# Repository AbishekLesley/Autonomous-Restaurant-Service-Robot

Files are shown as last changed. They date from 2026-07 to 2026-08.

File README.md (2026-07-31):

# 🤖 Autonomous Restaurant Service Robot

> An autonomous restaurant delivery robot developed to automate food delivery within indoor environments using magnetic-guided navigation, wireless communication, and embedded control systems.

---

## 📌 Overview

This project presents an autonomous service robot capable of navigating predefined paths inside restaurants while carrying food safely and efficiently. The robot integrates embedded systems, custom PCB design, motor control, wireless communication, and a mobile application into a complete autonomous platform.

### Key Features

- Autonomous restaurant delivery
- Magnetic path following using Hall-effect sensors
- Dual microcontroller architecture (ESP32-S3 + STM32)
- PID-based motor control
- Wireless communication
- Mobile application interface
- Obstacle detection
- Autonomous charging dock
- Custom-designed PCBs
- Custom enclosure design

---

## 🏗 System Architecture

<p align="center">
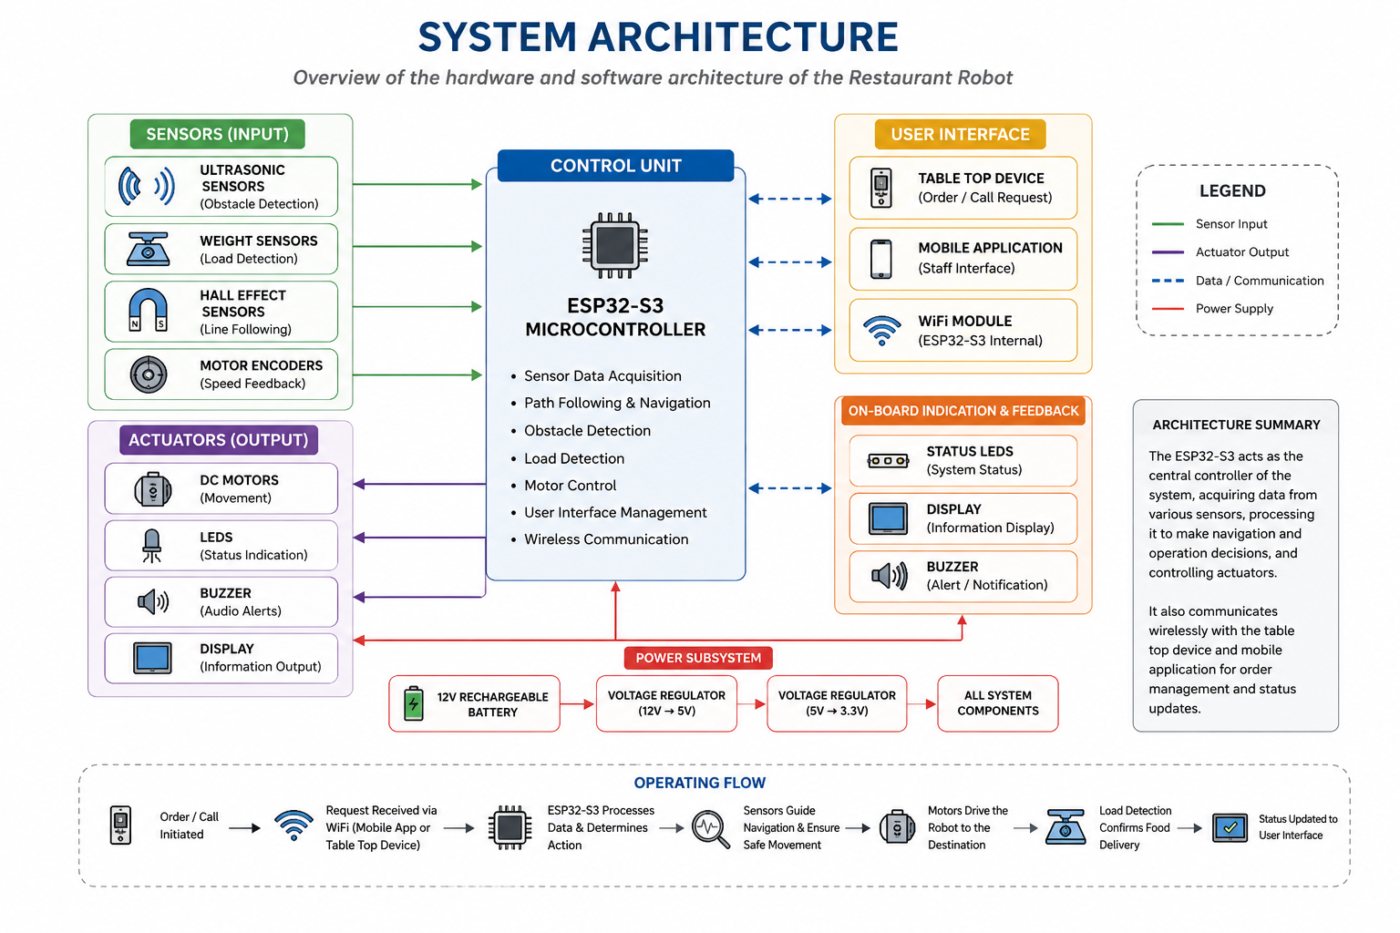
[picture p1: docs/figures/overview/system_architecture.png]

</p>

---

## 📷 Project Gallery

### Final Robot

<p align="center">
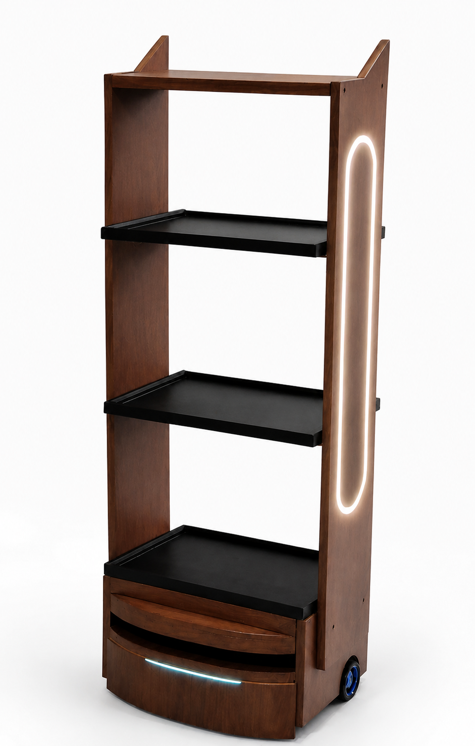
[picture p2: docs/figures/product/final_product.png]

</p>

### PCB Design

<p align="center">
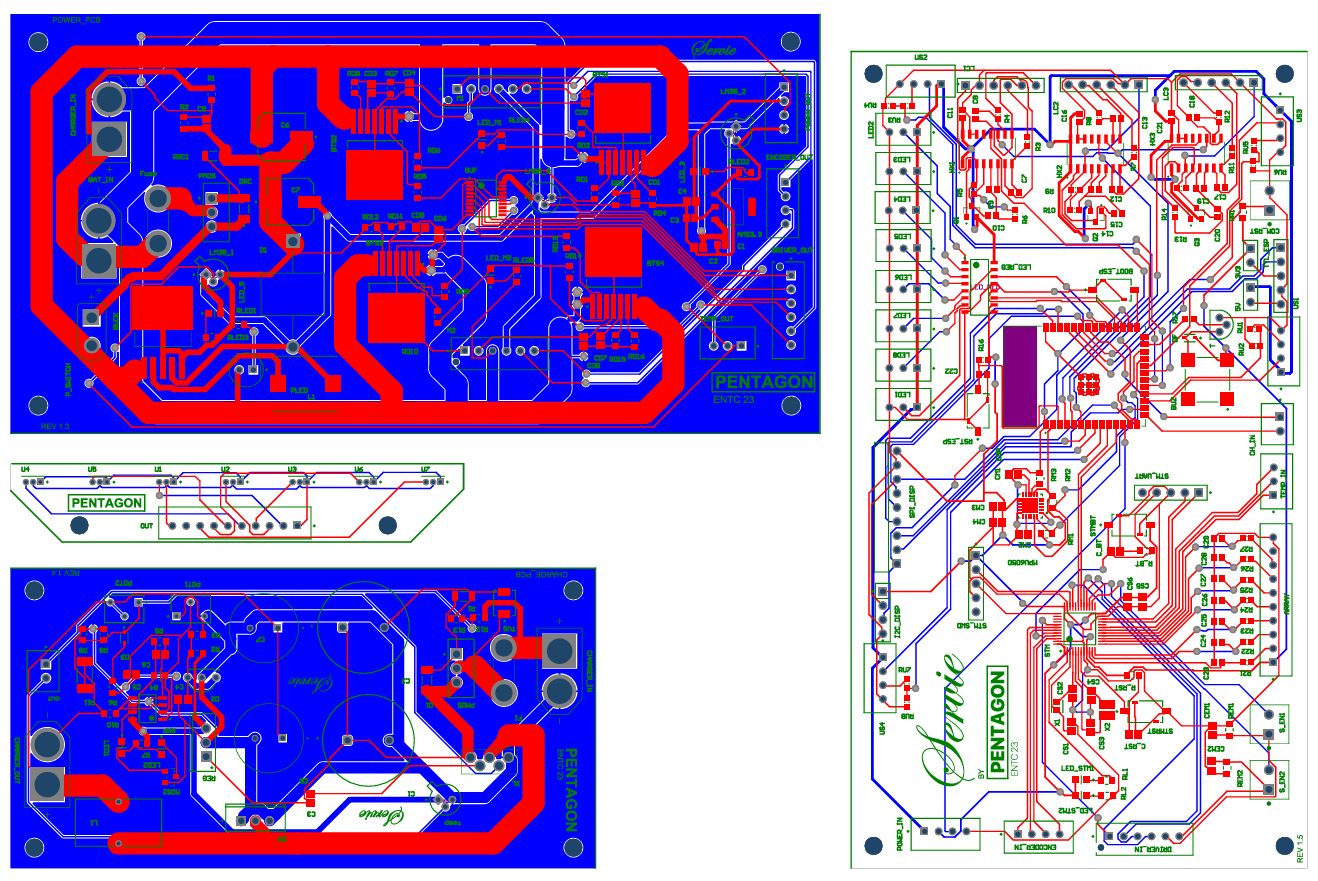
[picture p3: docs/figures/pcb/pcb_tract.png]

</p>

### Enclosure Design

<p align="center">
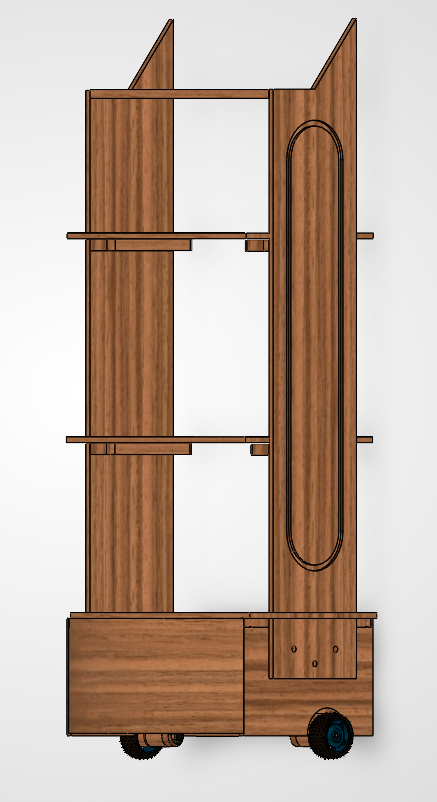
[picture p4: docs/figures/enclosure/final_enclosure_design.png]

</p>

---

## 🛠 Technologies

### Embedded Systems

- ESP32-S3
- STM32
- Embedded C
- Arduino Framework

### Electronics

- Altium Designer
- Custom PCB Design
- Hall Effect Sensors
- Motor Drivers

### Mechanical Design

- SolidWorks
- Custom Enclosure Design

## Architecture

```text
React/Vite web app --HTTP--> ESP32 --UART 115200 8N1--> STM32F103C8Tx
```

- `webapp/` contains the React dashboard. It connects to the ESP32 API at
  `http://192.168.4.1` by default.
- `firmware/esp32/` contains the Arduino sketch responsible for Wi-Fi, HTTP API,
  weight sensing, obstacle sensing, LEDs, and communication with the STM32.
- `firmware/stm32/` contains the STM32CubeIDE project responsible for line
  following, route execution, motors, encoders, Hall sensors, and docking.

## STM32 project

Target: STM32F103C8Tx

Import `firmware/stm32` with:

1. Open STM32CubeIDE and select a workspace outside this repository.
2. Select **File > Import > General > Existing Projects into Workspace**.
3. Select the `firmware/stm32` directory.
4. Leave **Copy projects into workspace** unchecked.
5. Build and flash using the appropriate hardware debugger.

The CubeMX configuration is `pentagon_new.ioc`.

## ESP32 project

Open `firmware/esp32/esp32_robot_api_led_control_v13.ino` with the Arduino IDE.
Select the exact installed ESP32 board before compiling. In addition to the
ESP32 Arduino core, the sketch requires these libraries:

- HX711
- Adafruit NeoPixel

The ESP32 communicates with the STM32 through UART1 at 115200 baud:

- ESP32 RX: GPIO 18
- ESP32 TX: GPIO 17

## Web application

Requires Node.js and npm.

```powershell
cd webapp
npm install
npm run dev
```

For a production build:

```powershell
npm run build
```

Connect the controlling device to `RestaurantRobot_AP`, then open the dashboard
and use `http://192.168.4.1` as the ESP32 address.

## Safety and configuration

- Test motion changes with the wheels raised or motors mechanically isolated
  before floor testing.
- Confirm that the stop command and obstacle handling work before route tests.
- Pin assignments and calibration constants currently live in the firmware
  source files.
- The ESP32 firmware currently contains a development access-point password.
  Replace it with a deployment-specific secret before operating in a public
  environment, and do not commit real venue Wi-Fi credentials.

---

## 📁 Repository Structure

```text
Autonomous-Restaurant-Service-Robot/
│
├── docs/
│   ├── figures/
│   ├── reports/
│   ├── schematics/
│   └── working_videos/
│
├── hardware/
│   ├── enclosure/
│   ├── pcb-design/
│   └── pcb-3d-models/
│
├── firmware/
│   ├── esp32/
│   ├── stm32/
│   └── arduino/
│
├── mobile-app/
│
├── README.md
├── LICENSE
└── .gitignore
```

---

## 📄 Documentation

Project documentation can be found in:

- Final Report
- Final Presentation
- Project Pitch
- PCB Schematics
- Working Videos

located under the **docs/** directory.

---

## 👥 Team Members

- **Abishek L.**
- **Santhosh S.**
- **Umair A.**
- **Hakam M. R. A.**
- **Nuwanaka W. A. S.**

---

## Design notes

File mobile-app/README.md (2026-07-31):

# Restaurant Robot React UI - V21 Ultrasonic Obstacle

Adds:
- Staff obstacle card with front/left/right readings.
- Robot icon red boundary glow while obstacle stop/help is active.
- Bypass for current journey from Staff page.
- Technical page ultrasonic sensor enable/disable and bypass tools.
- Technical page Hall read/update buttons.

Current repository integration:
- ESP32: `../firmware/esp32/esp32_robot_api_led_control_v13.ino`
- STM32: `../firmware/stm32/Core/Src/main.c`

## V24 LED control fix

The LED modal now keeps local slider, color, brightness, speed, pattern, zone, and link-side edits while the dashboard continues polling `/api/status`. Press **Apply settings** to send the selected values to the ESP32. Background status refreshes no longer reset the controls to defaults.

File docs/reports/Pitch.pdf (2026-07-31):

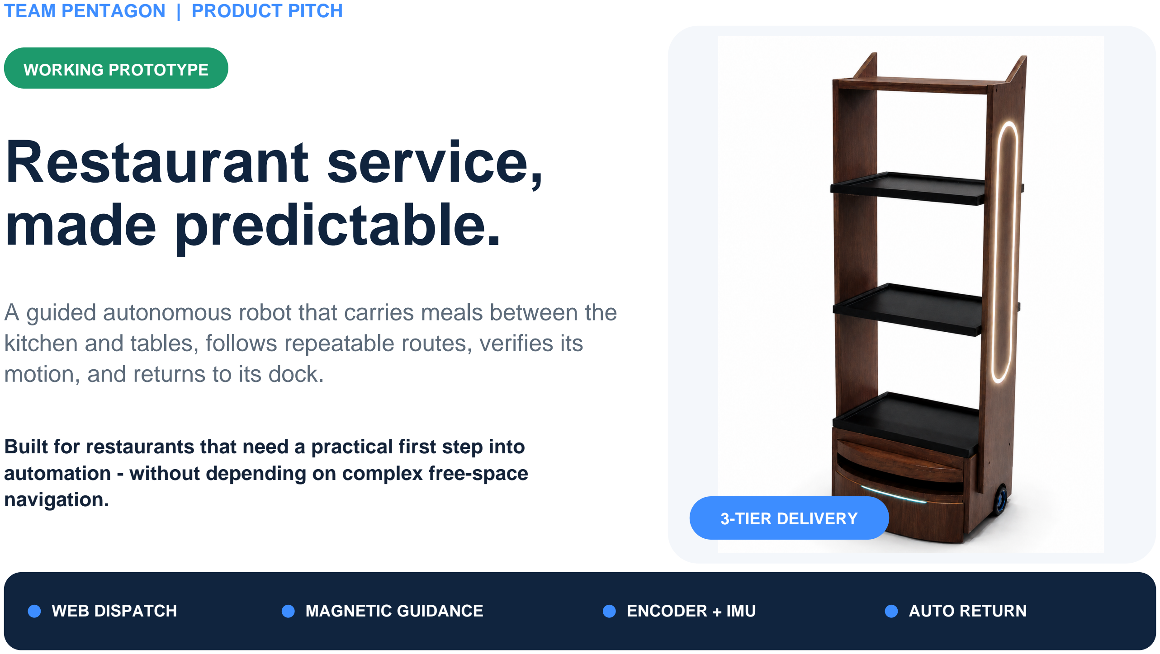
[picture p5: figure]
TEAM PENTAGON | PRODUCT PITCH; WORKING PROTOTYPE Restaurant service, made predictable.; motion, and returns to its dock.; navigation.; 3-TIER DELIVERY; WEB DISPATCH; MAGNETIC GUIDANCE; ENCODER + IMU; AUTO RETURN

## A guided autonomous robot that carries meals between the kitchen and tables, follows repeatable routes, verifies its

### Built for restaurants that need a practical first step into automation - without depending on complex free-space

# A reliable path from kitchen to table

THE OPERATIONAL PROBLEM

## Repetitive delivery pulls staff away from

guests.

Reliability determines whether automation adds value.

OUR APPROACH

## Constrain the route, verify movement, and

recover within limits.

Designed for repeatability and easier deployment.

### 01 Sense the route

Seven Hall sensors detect the magnetic line and route markers for centering, junction recognition, and stopping.

### 02 Verify motion

Wheel encoders check segment distance while the MPU6050 controls repeatable 90 and 180 degree turns.

### 03 Recover safely

Line-loss recovery, bounded search windows, motor stop logic, and dock confirmation handle common faults.

PROTOTYPE STATUS

# Core navigation is running on hardware

PID line following | Table-2 round trip | IMU turns
Encoder distance checks | Dock and charger detection

NEXT MILESTONES

### 1 Engineering validation 2 Restaurant pilot 3 Production-ready electronics

THE ASK | Seeking a restaurant pilot partner and support for production electronics, safety validation, and manufacturing.
TEAM PENTAGON | Hakam M.R.A - 230334V | Umair A. - 230654M | Abishek L - 230016 Nuwanaka W.A.S - 230449N | Santhosh S - 230581K

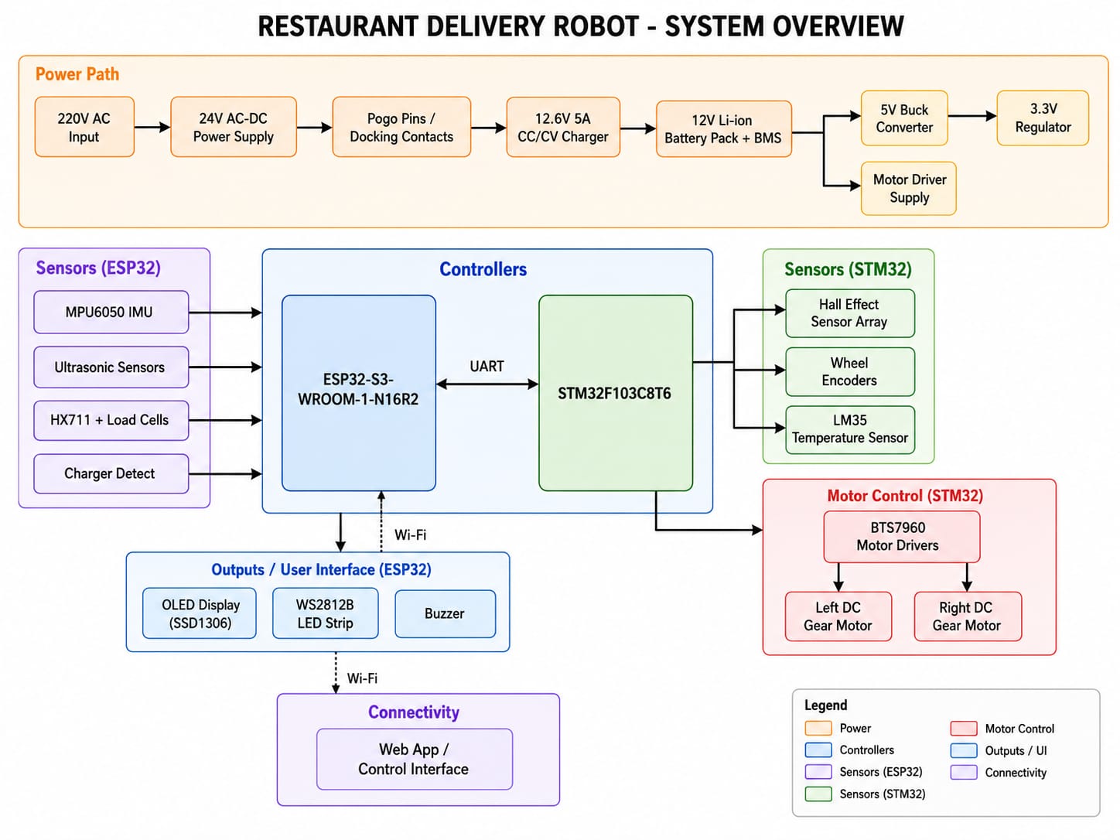
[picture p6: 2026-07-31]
docs/figures/overview/system_overview.jpeg

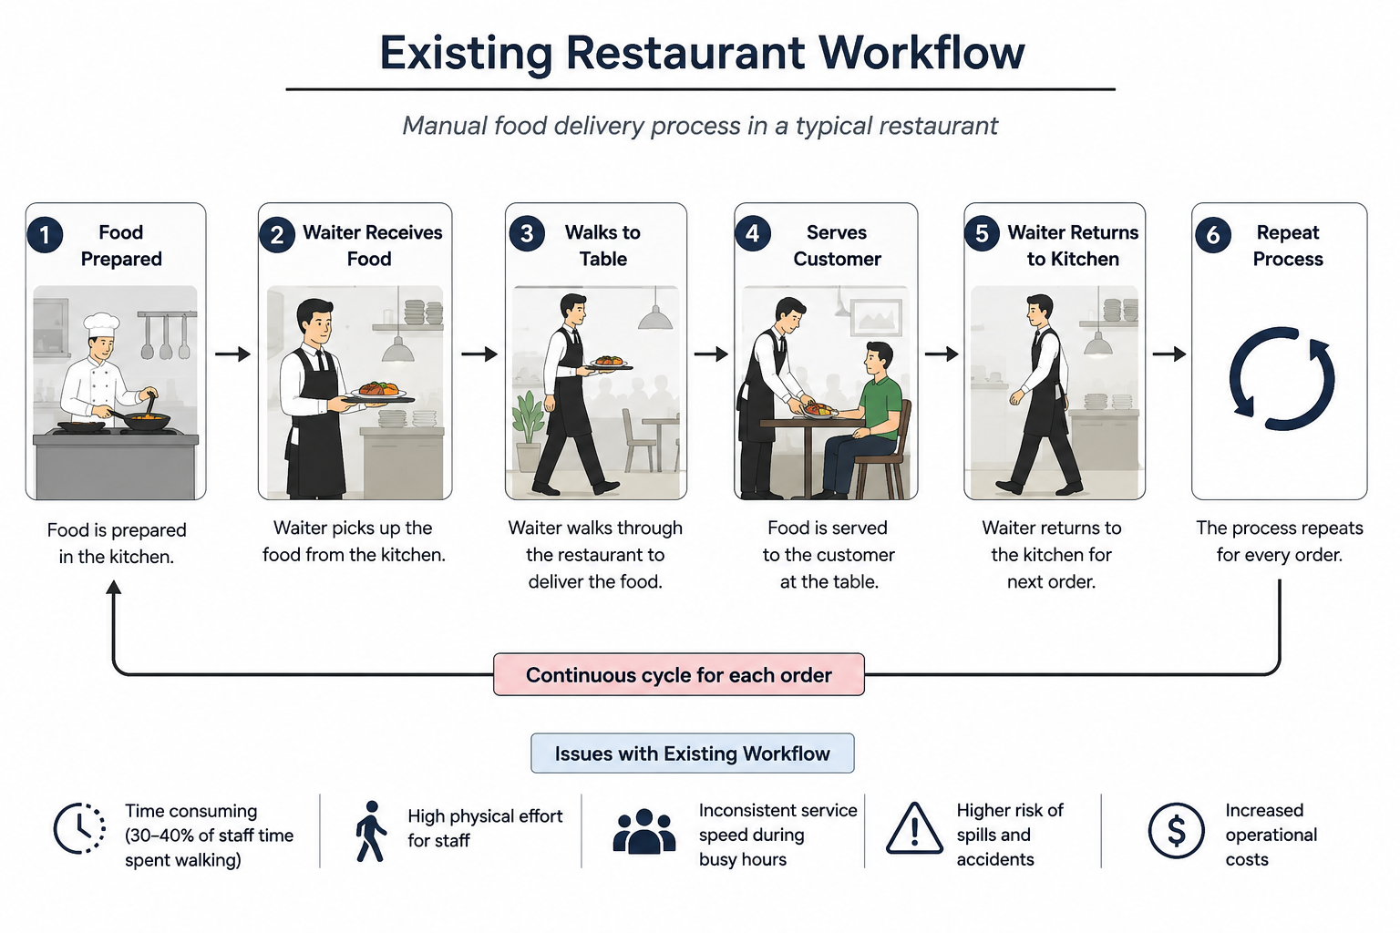
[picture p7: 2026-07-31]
docs/figures/overview/existing_workflow.png

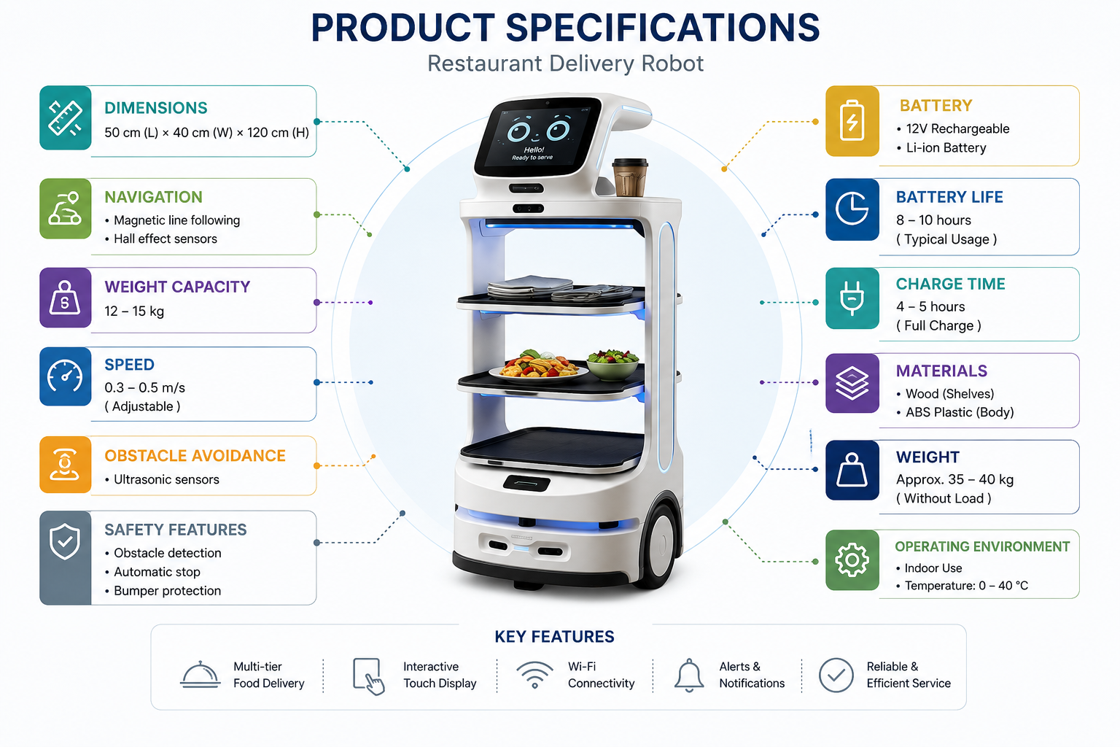
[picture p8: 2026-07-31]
docs/figures/overview/product_specification.png

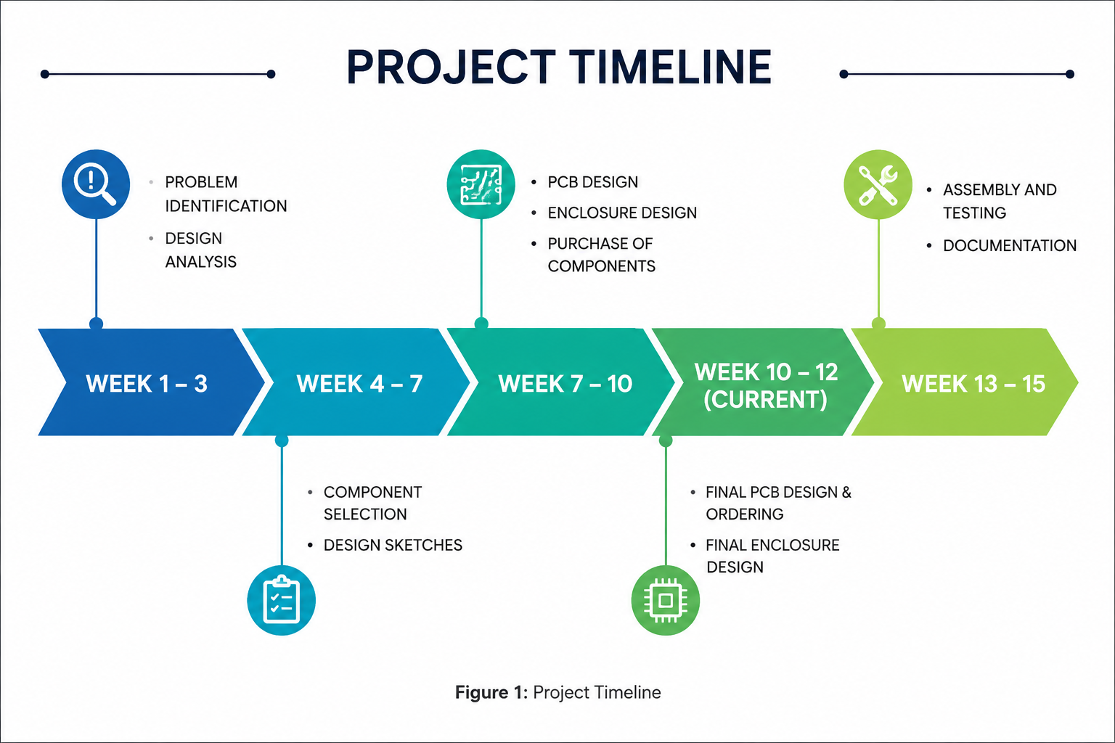
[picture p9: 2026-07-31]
docs/figures/overview/timeline.png

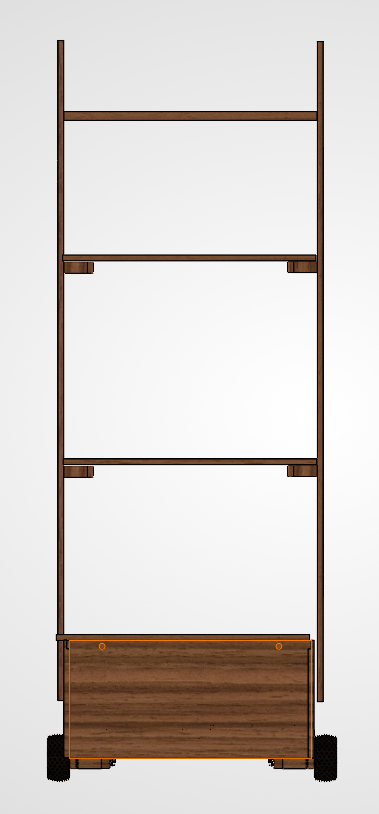
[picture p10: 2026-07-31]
docs/figures/enclosure/back 1.png

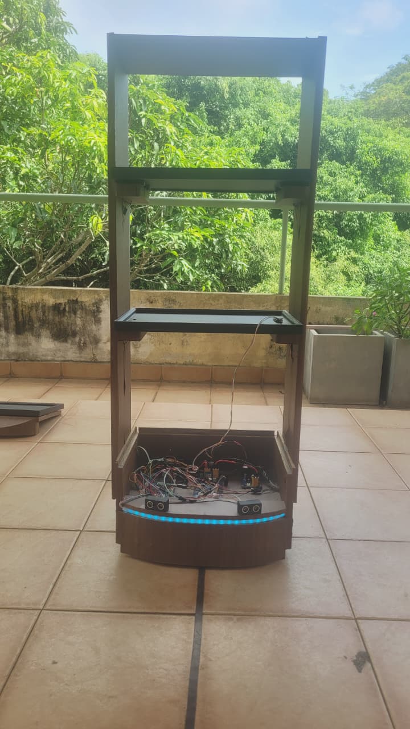
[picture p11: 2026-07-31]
docs/figures/product/Front.jpeg

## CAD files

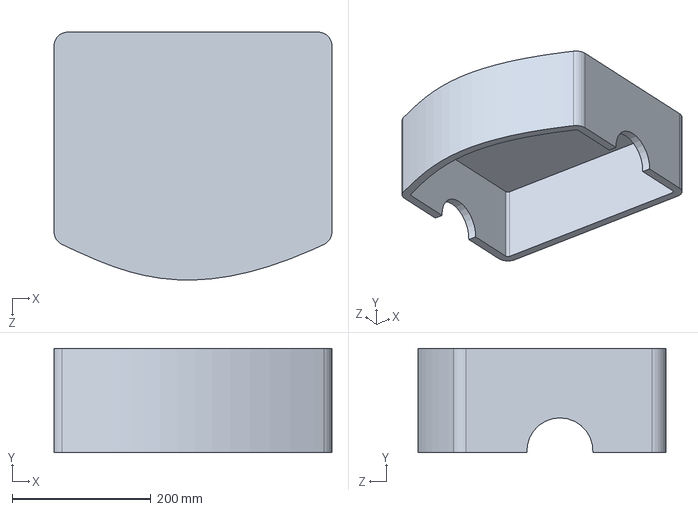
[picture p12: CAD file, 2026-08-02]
Hardware/enclosure/Base_Final_Design.SLDPRT
400.0 x 150.0 x 356.7 mm

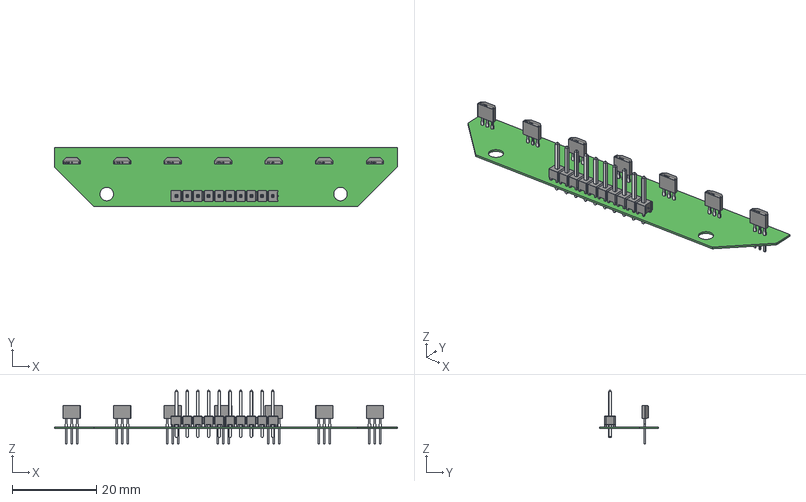
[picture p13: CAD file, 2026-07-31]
Hardware/pcb-3d-models/halleffect.step
81.4 x 14.1 x 12.7 mm
terminal x 7
logo x 7
TSW-110-07-T-S_body
T-1S6-07-TSW-1-07-10-S
Samtec

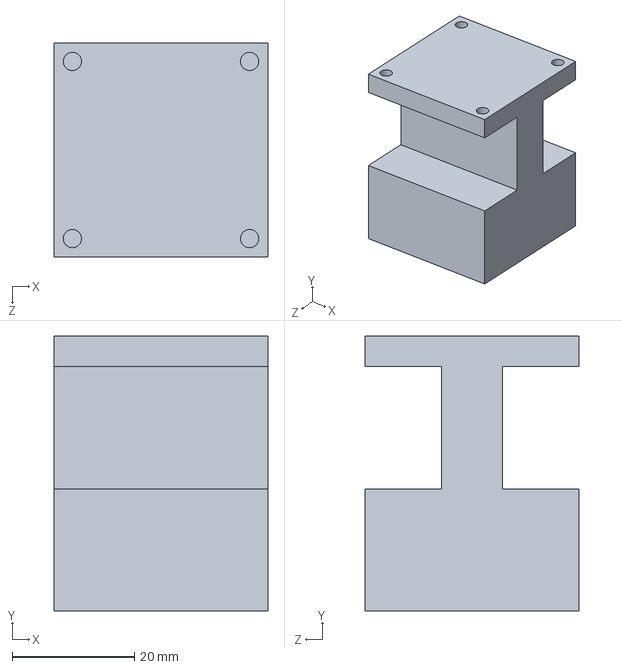
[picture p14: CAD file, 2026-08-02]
Hardware/enclosure/Caster wheel holder.SLDPRT
35.0 x 45.0 x 35.0 mm

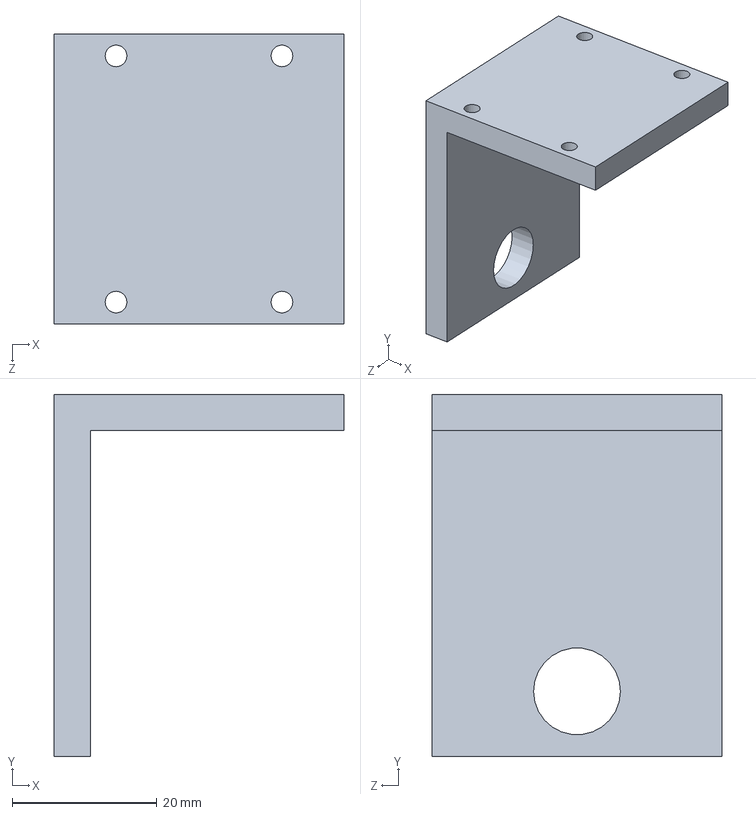
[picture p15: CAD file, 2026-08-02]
Hardware/enclosure/Motor_handle.SLDPRT
40.0 x 50.0 x 40.0 mm

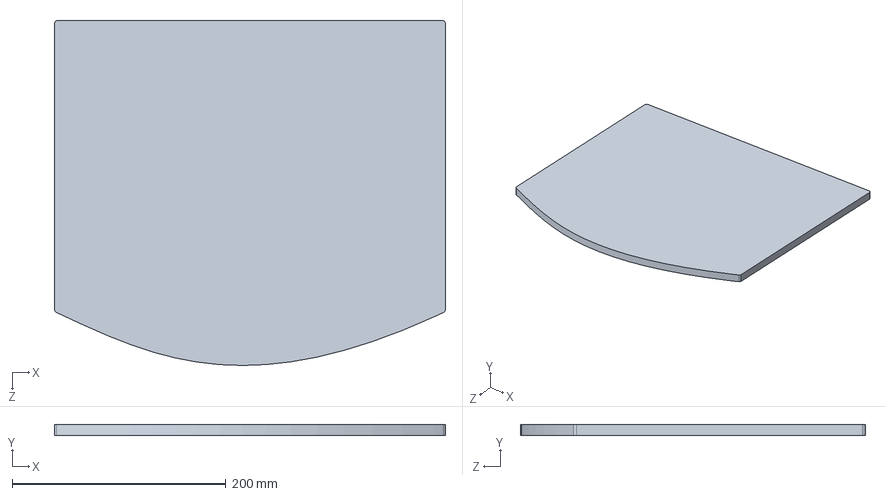
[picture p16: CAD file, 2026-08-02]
Hardware/enclosure/Pcb_Board Final.SLDPRT
366.0 x 10.0 x 322.9 mm

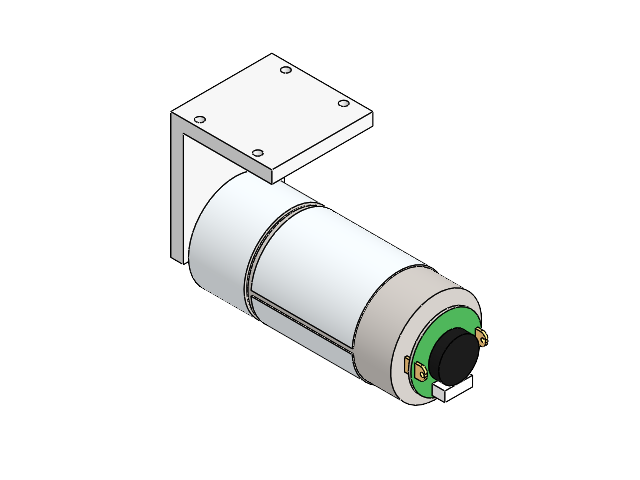
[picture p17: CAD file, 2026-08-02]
Hardware/enclosure/Motor handle + motor.SLDASM
Motor_handle
JGB37-555
TRUCMOTOR

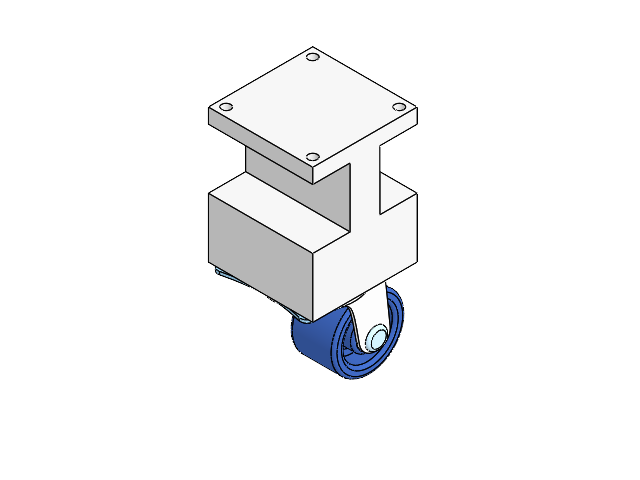
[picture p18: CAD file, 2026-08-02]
Hardware/enclosure/Caster full kit.SLDASM
Caster wheel holder
Castor Wheel Assembly 24mm diameter wheel part

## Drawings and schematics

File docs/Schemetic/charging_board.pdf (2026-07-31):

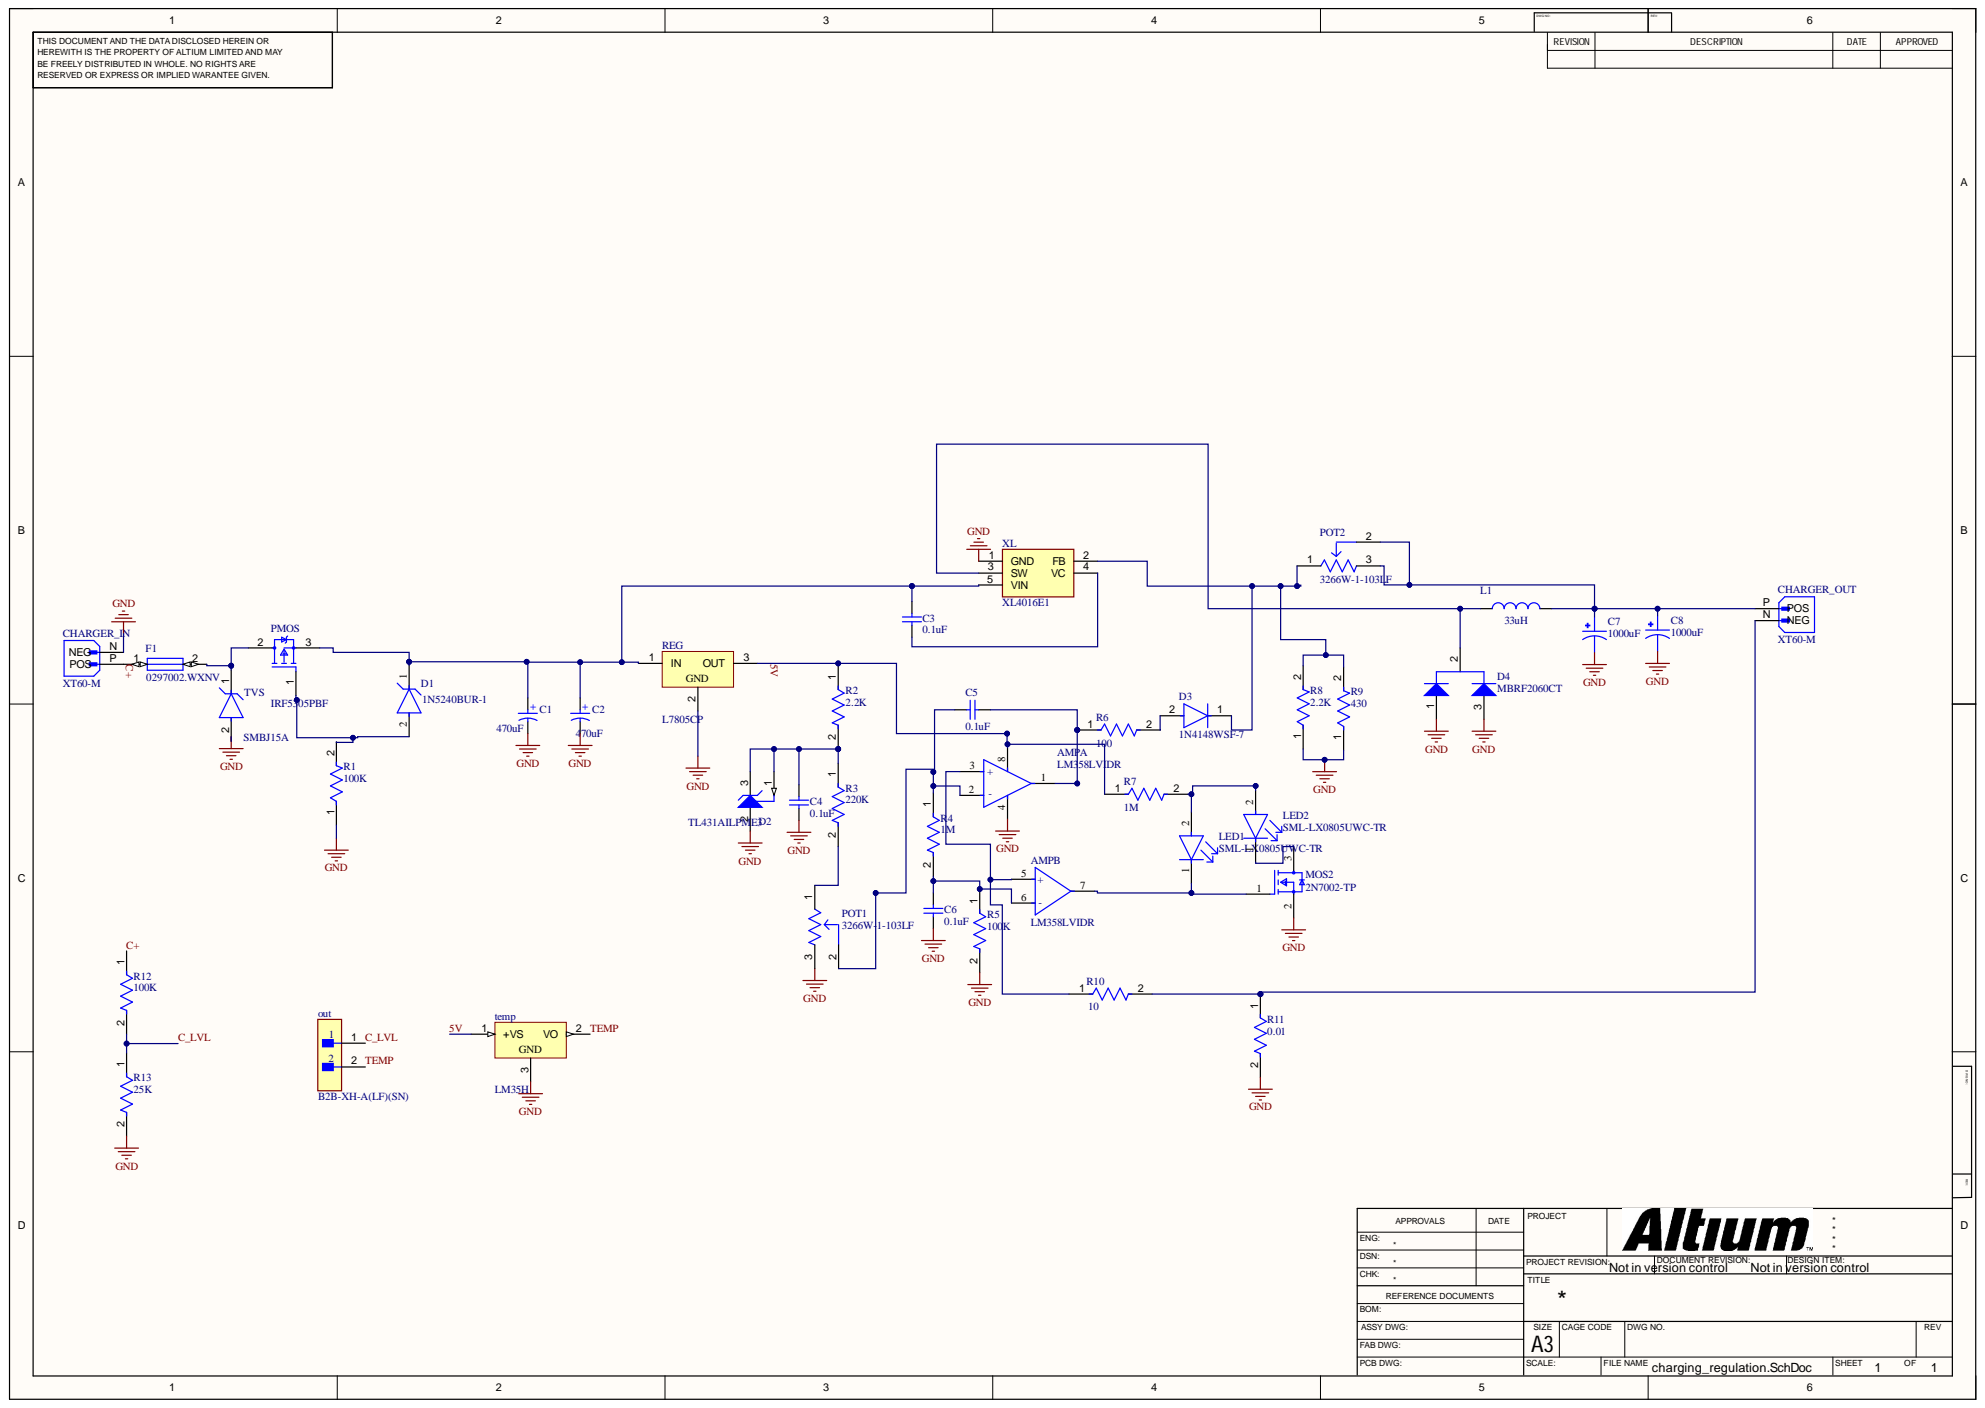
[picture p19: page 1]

THIS DOCUM ENT AND THE DATA DISCLOS ED HEREIN OR HERE WITH IS THE PROP ERT Y OF A LTIUM LIMIT ED AND M AY B E FRE E LY DIS TRIBUT ED IN WHOL E. NO RIGHT S ARE RE S ERV ED OR E X PRE S S OR IM P LIED W ARANT E E GIV EN. | | R E V I S I ON | D E S C R I PT I ON | D AT E | A P P R OVE D

A P PROV A L S | DAT E | PROJECT | ****

ENG: **
CHK : | | TIT L E *

DSN: | | PROJECT RE VISION: Not i n v | DOCUM ENT RE VISION: ers i o n c o ntro l Not i n | DE SIGN IT E M : v ers i o n c o ntro l

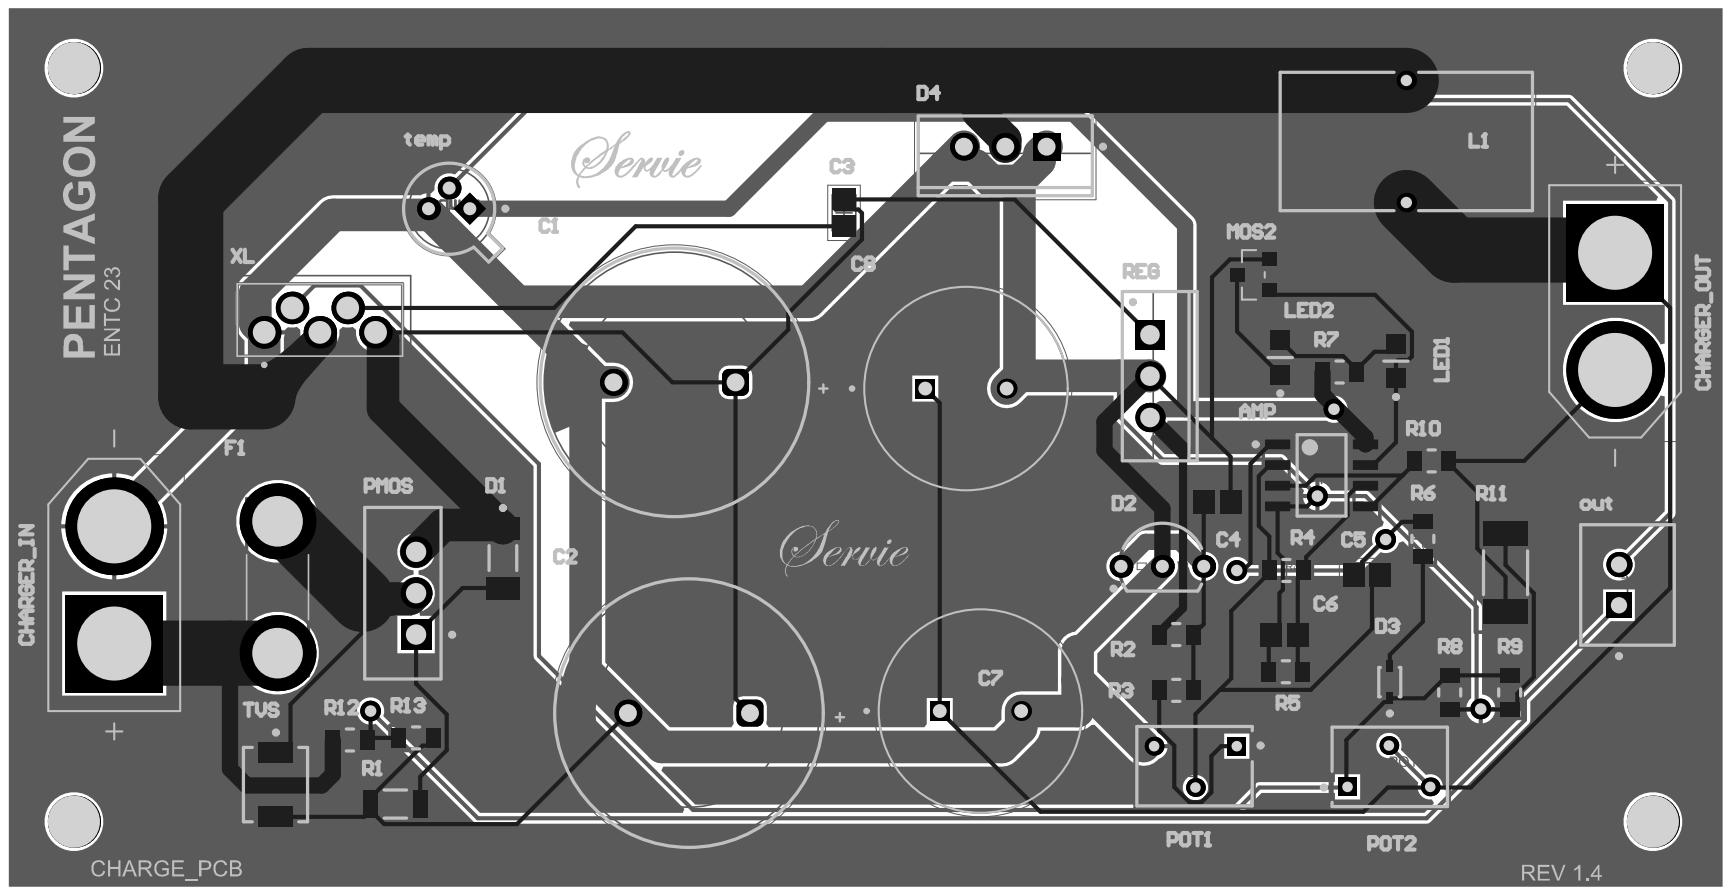
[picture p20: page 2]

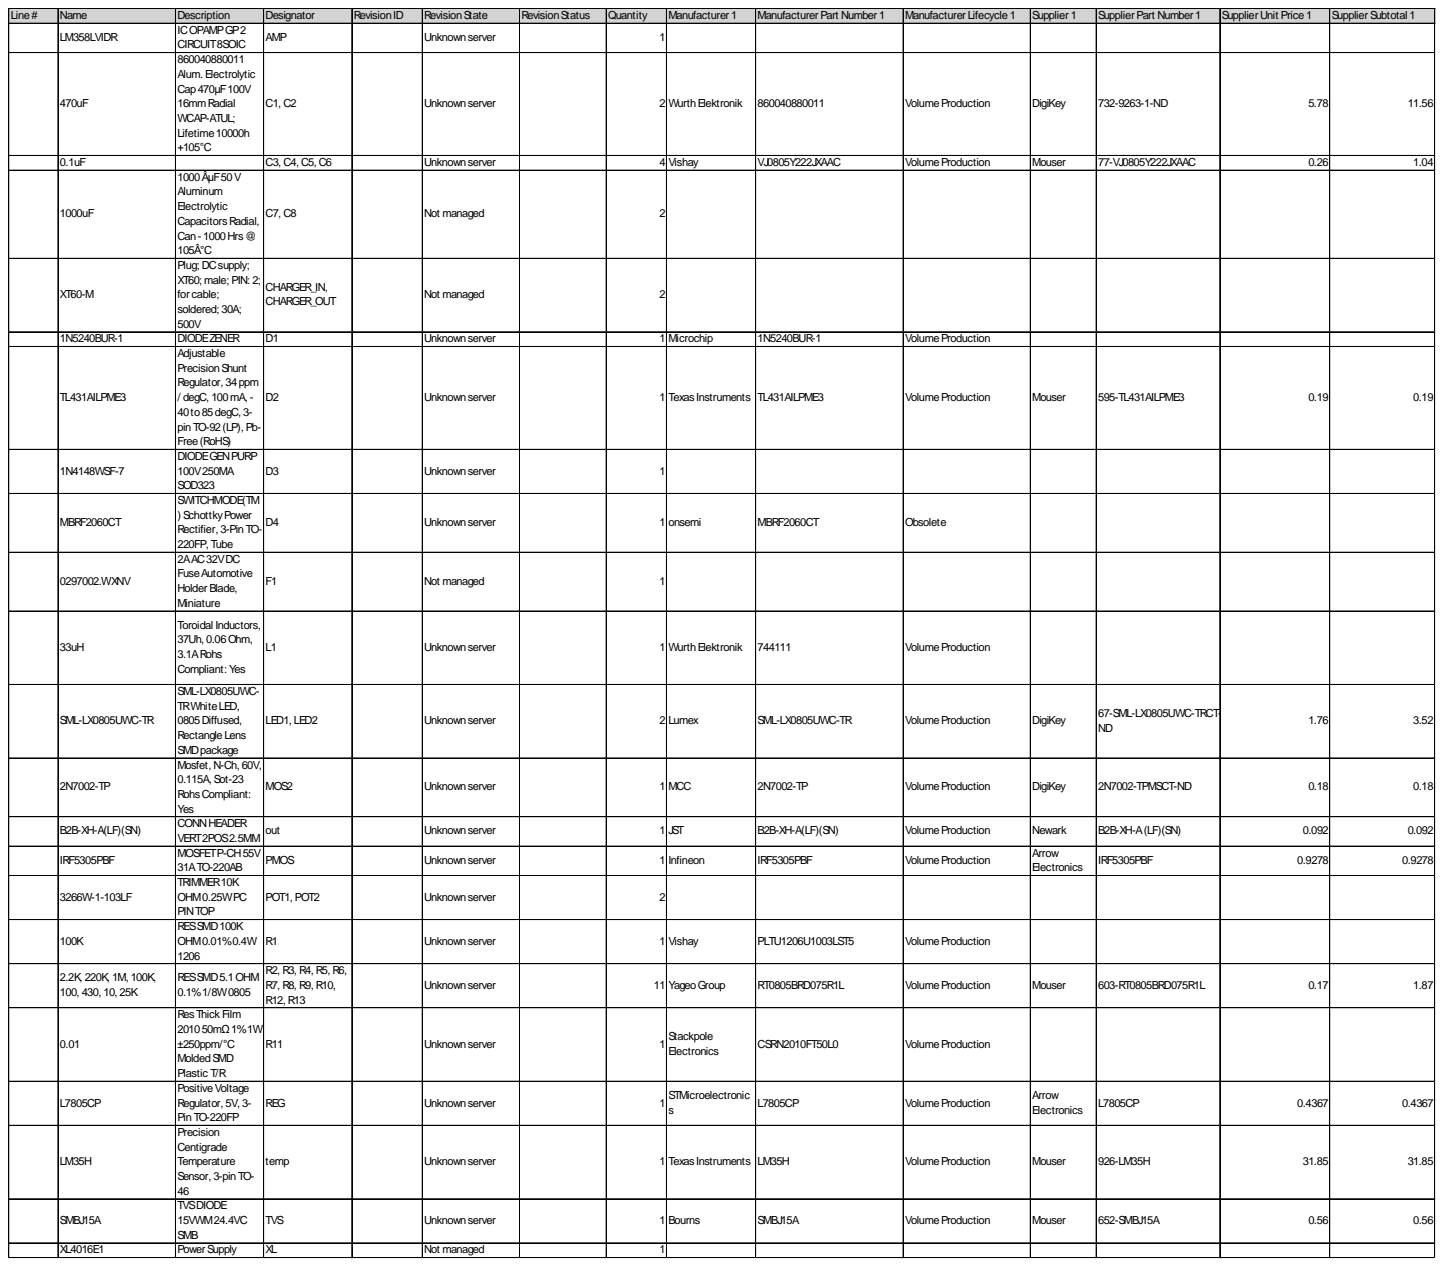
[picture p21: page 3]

Line# | Name | Description | Designator | RevisionID | RevisionState | RevisionStatus | Quantity | Manufacturer 1 | Manufacturer Part Number 1 | Manufacturer Lifecycle 1 | Supplier 1 | Supplier Part Number 1 | Supplier Unit Price 1 | Supplier Subtotal 1

LM358LVIDR | ICOPAMPGP2 CIRCUIT8SOIC | AMP | | Unknownserver | | 1

470uF | 860040880011 Alum. Electrolytic Cap470µF100V 16mmRadial WCAP-ATUL; Lifetime10000h +105°C | C1, C2 | | Unknownserver | | 2 WurthElektronik | | 860040880011 | VolumeProduction | DigiKey | 732-9263-1-ND | 5.78 | 11.56

0.1uF | | C3, C4, C5, C6 | | Unknownserver | | 4 Vishay | | VJ0805Y222JXAAC | VolumeProduction | Mouser | 77-VJ0805Y222JXAAC | 0.26 | 1.04
1000uF | 1000ÂµF50V Aluminum Electrolytic CapacitorsRadial, Can- 1000Hrs@ 105Â°C | C7, C8 | | Not managed | | 2

XT60-M | Plug; DCsupply; XT60; male; PIN: 2; for cable; soldered; 30A; 500V | CHARGER_IN, CHARGER_OUT | | Not managed | | 2

1N5240BUR-1 | DIODEZENER | D1 | | Unknownserver | | 1 Microchip | | 1N5240BUR-1 | VolumeProduction
TL431AILPME3 | Adjustable PrecisionShunt Regulator, 34ppm / degC, 100mA, -40to85degC, 3-pin TO-92(LP), Pb-Free(RoHS) | D2 | | Unknownserver | | 1 Texas Instruments | | TL431AILPME3 | VolumeProduction | Mouser | 595-TL431AILPME3 | 0.19 | 0.19

1N4148WSF-7 | DIODEGENPURP 100V250MA SOD323 | D3 | | Unknownserver | | 1

MBRF2060CT | SWITCHMODE(TM ) SchottkyPower Rectifier, 3-Pin TO-220FP, Tube | D4 | | Unknownserver | | 1 onsemi | | MBRF2060CT | Obsolete

0297002.WXNV | 2AAC32VDC FuseAutomotive Holder Blade, Miniature | F1 | | Not managed | | 1

33uH | Toroidal Inductors, 37Uh, 0.06Ohm, 3.1ARohs Compliant: Yes | L1 | | Unknownserver | | 1 WurthElektronik | | 744111 | VolumeProduction

SML-LX0805UWC-TR | SML-LX0805UWC-TRWhiteLED, 0805Diffused, Rectangle Lens SMDpackage | LED1, LED2 | | Unknownserver | | 2 Lumex | | SML-LX0805UWC-TR | VolumeProduction | DigiKey | 67-SML-LX0805UWC-TRCT-ND | 1.76 | 3.52

2N7002-TP | Mosfet, N-Ch, 60V, 0.115A, Sot-23 RohsCompliant: Yes | MOS2 | | Unknownserver | | 1 MCC | | 2N7002-TP | VolumeProduction | DigiKey | 2N7002-TPMSCT-ND | 0.18 | 0.18

B2B-XH-A(LF)(SN) | CONNHEADER VERT2POS2.5MM | out | | Unknownserver | | 1 JST | | B2B-XH-A(LF)(SN) | VolumeProduction | Newark | B2B-XH-A(LF)(SN) | 0.092 | 0.092

IRF5305PBF | MOSFETP-CH55V 31ATO-220AB | PMOS | | Unknownserver | | 1 Infineon | | IRF5305PBF | VolumeProduction | Arrow Electronics | IRF5305PBF | 0.9278 | 0.9278

3266W-1-103LF | TRIMMER10K OHM0.25WPC PINTOP | POT1, POT2 | | Unknownserver | | 2

100K | RESSMD100K OHM0.01%0.4W 1206 | R1 | | Unknownserver | | 1 Vishay | | PLTU1206U1003LST5 | VolumeProduction

2.2K, 220K, 1M, 100K, 100, 430, 10, 25K | RESSMD5.1OHM 0.1%1/8W0805 | R2, R3, R4, R5, R6, R7, R8, R9, R10, R12, R13 | | Unknownserver | | 11 YageoGroup | | RT0805BRD075R1L | VolumeProduction | Mouser | 603-RT0805BRD075R1L | 0.17 | 1.87

0.01 | ResThick Film 201050mΩ1%1W ±250ppm/°C MoldedSMD Plastic T/R | R11 | | Unknownserver | | 1 Stackpole | Electronics | CSRN2010FT50L0 | VolumeProduction

L7805CP | PositiveVoltage Regulator, 5V, 3-Pin TO-220FP | REG | | Unknownserver | | 1 STMicroelectronic | s | L7805CP | VolumeProduction | Arrow Electronics | L7805CP | 0.4367 | 0.4367

LM35H | Precision Centigrade Temperature Sensor, 3-pin TO-46 | temp | | Unknownserver | | 1 Texas Instruments | | LM35H | VolumeProduction | Mouser | 926-LM35H | 31.85 | 31.85

SMBJ15A | TVSDIODE 15VWM24.4VC SMB | TVS | | Unknownserver | | 1 Bourns | | SMBJ15A | VolumeProduction | Mouser | 652-SMBJ15A | 0.56 | 0.56

XL4016E1 | Power Supply | XL | | Not managed | | 1

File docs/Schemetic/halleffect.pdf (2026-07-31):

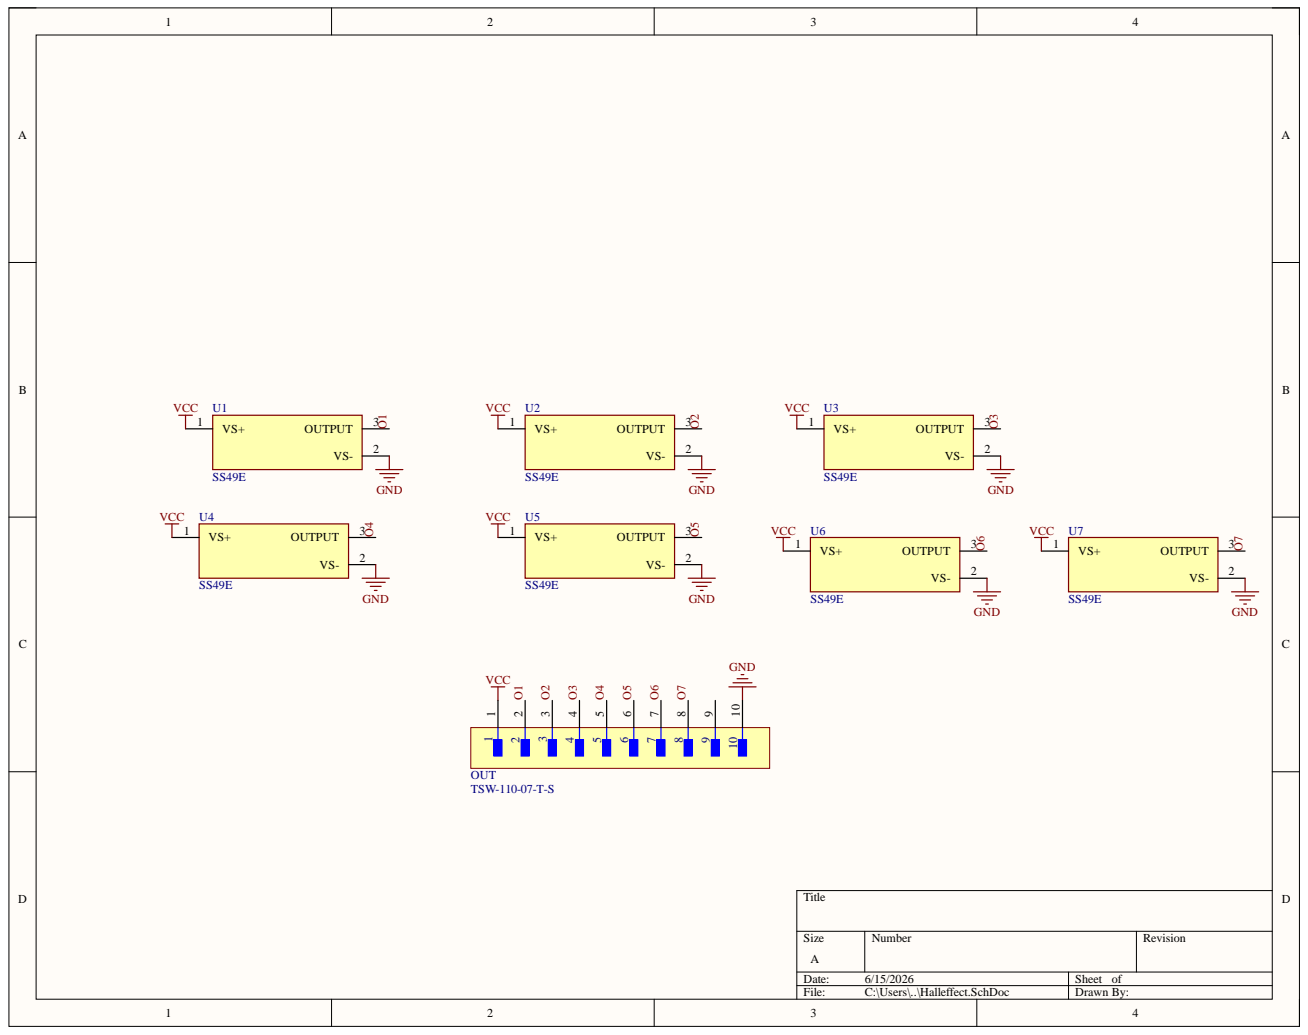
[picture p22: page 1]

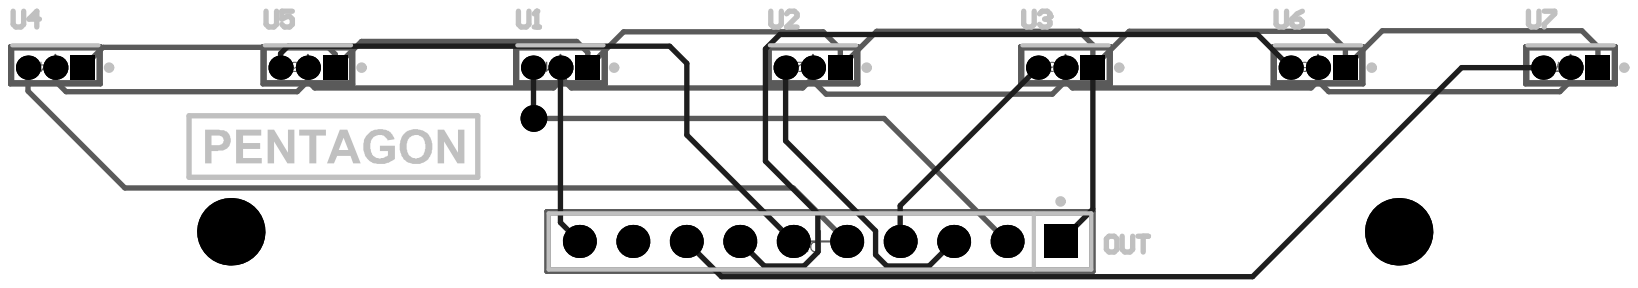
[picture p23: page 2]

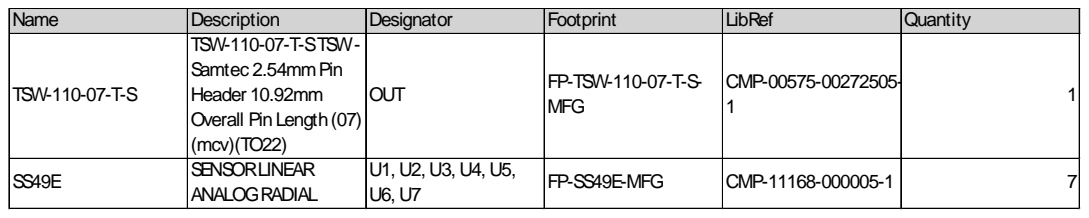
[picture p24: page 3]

Name | Description | Designator | Footprint | LibRef | Quantity
TSW-110-07-T-S | TSW-110-07-T-STSW-Samtec 2.54mmPin Header 10.92mm Overall Pin Length(07) (mcv)(TO22) | OUT | FP-TSW-110-07-T-S-MFG | CMP-00575-00272505-1 | 1

SS49E | SENSORLINEAR ANALOGRADIAL | U1, U2, U3, U4, U5, U6, U7 | FP-SS49E-MFG | CMP-11168-000005-1 | 7

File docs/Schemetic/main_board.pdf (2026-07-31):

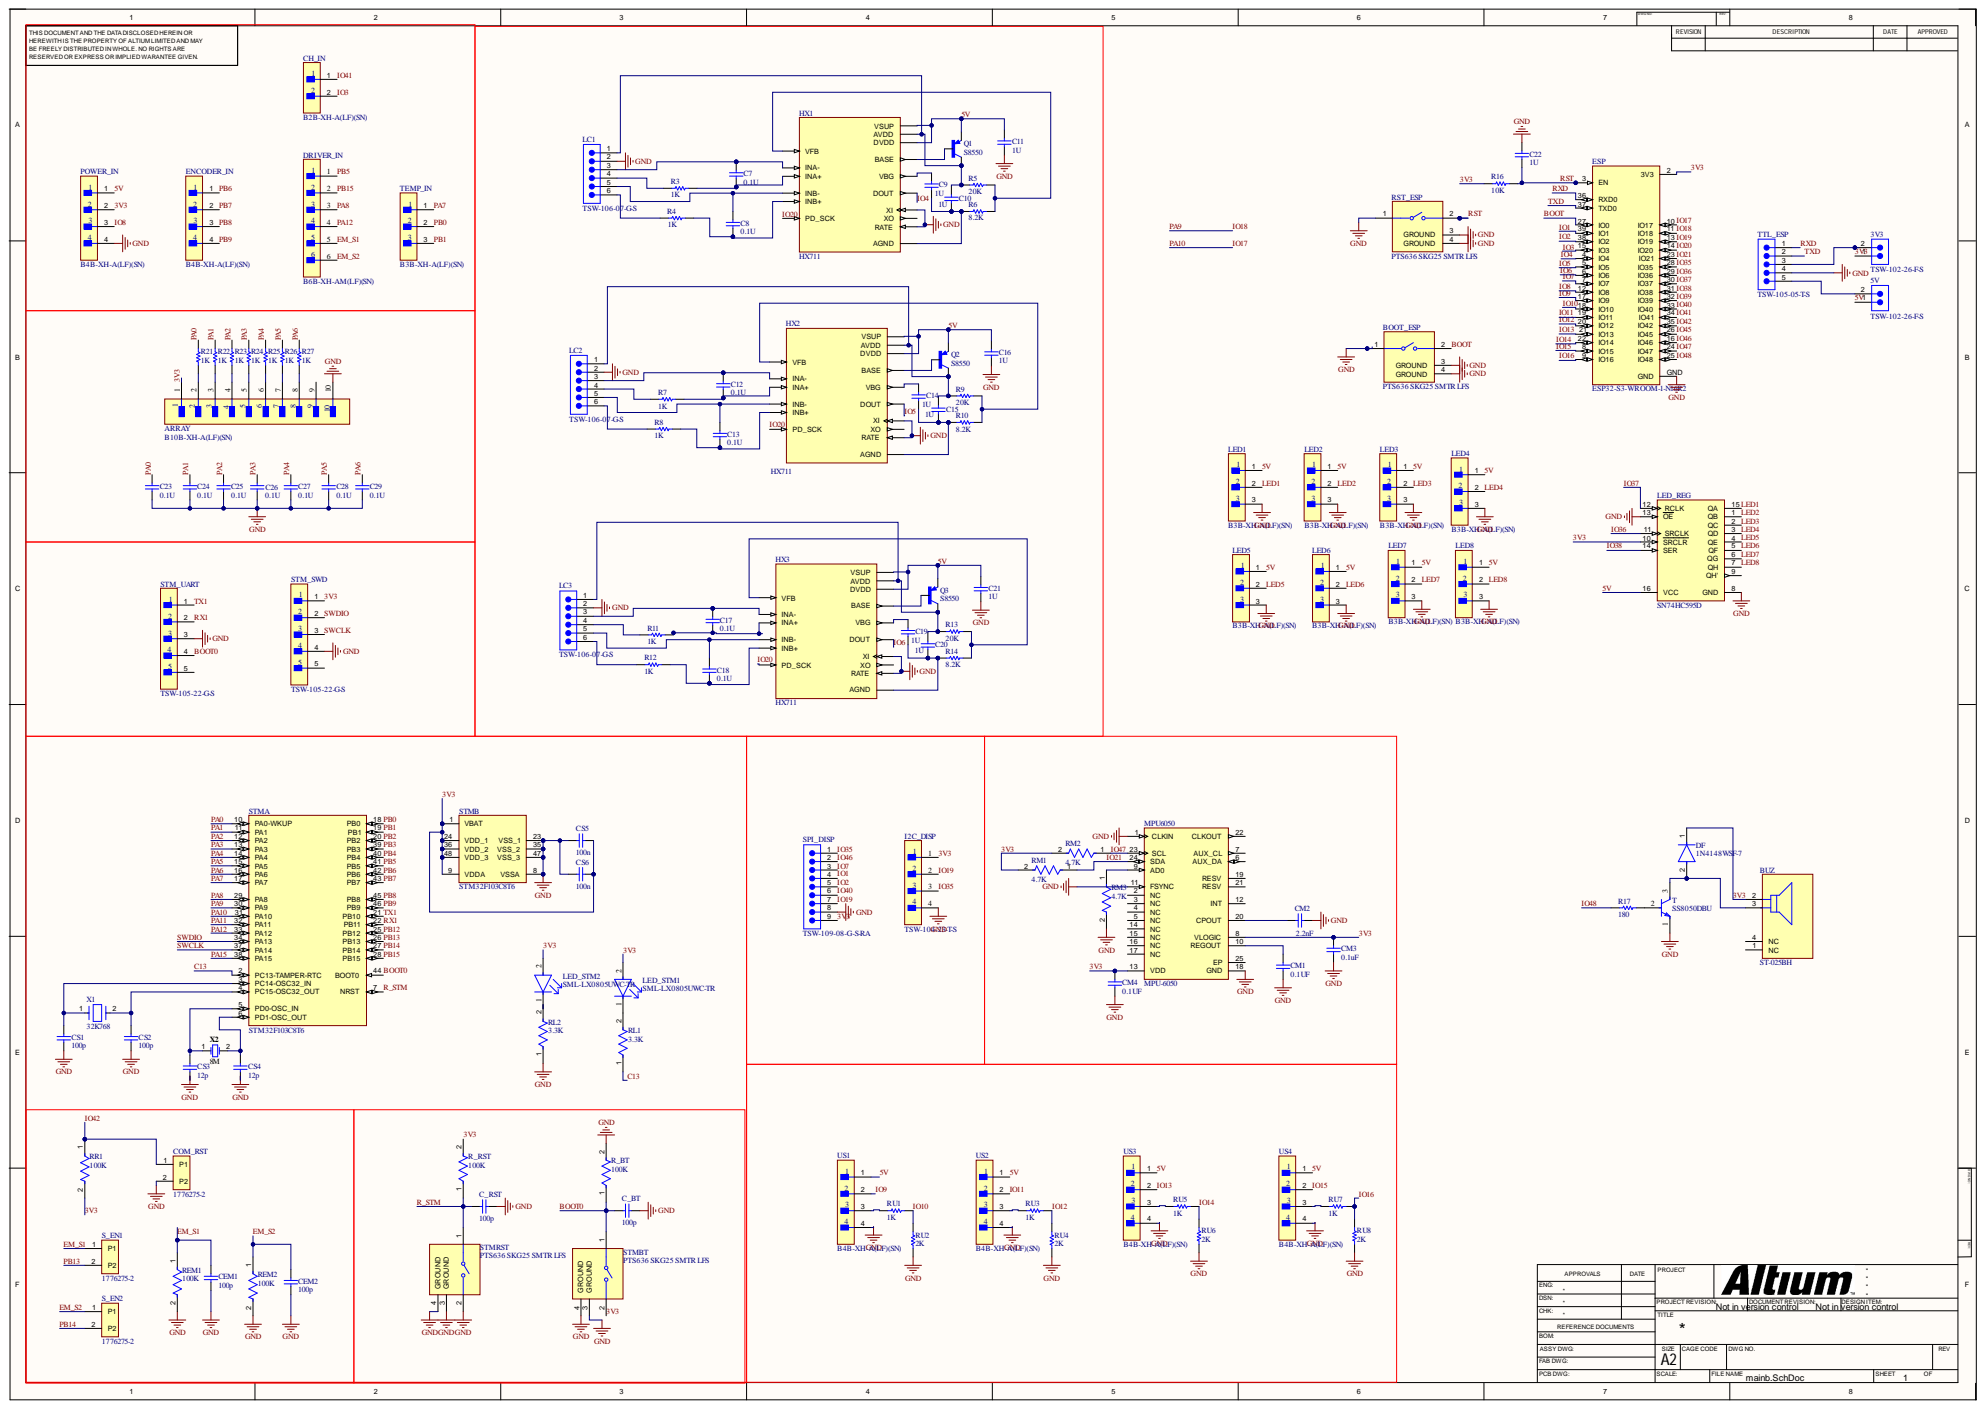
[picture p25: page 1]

1 | 2 | 3 | 4 | 5 | 6 | 7 | DWG NO: | REV: | 8

THIS DOCUMENT AND THE DATADISCLOSED HEREIN OR HEREWITH IS THE PROPERTY OF ALTIUM LIMITED AND MAY BE FREELY DISTRIBUTED IN WHOLE. NO RIGHTS ARE RESERVED OR EXPRESS OR IMPLIED WARANTEE GIVEN. | CH_IN | | GND C22 ESP LED1 LED2 | REVISION | DESCRIPTION | DATE | APPROVED

2 | GND | BASE INA-INA+ VBG INB-DOUT INB+ XI PD_SCK XO RATE AGND

3V3 | I2C_DISP | MPU6050

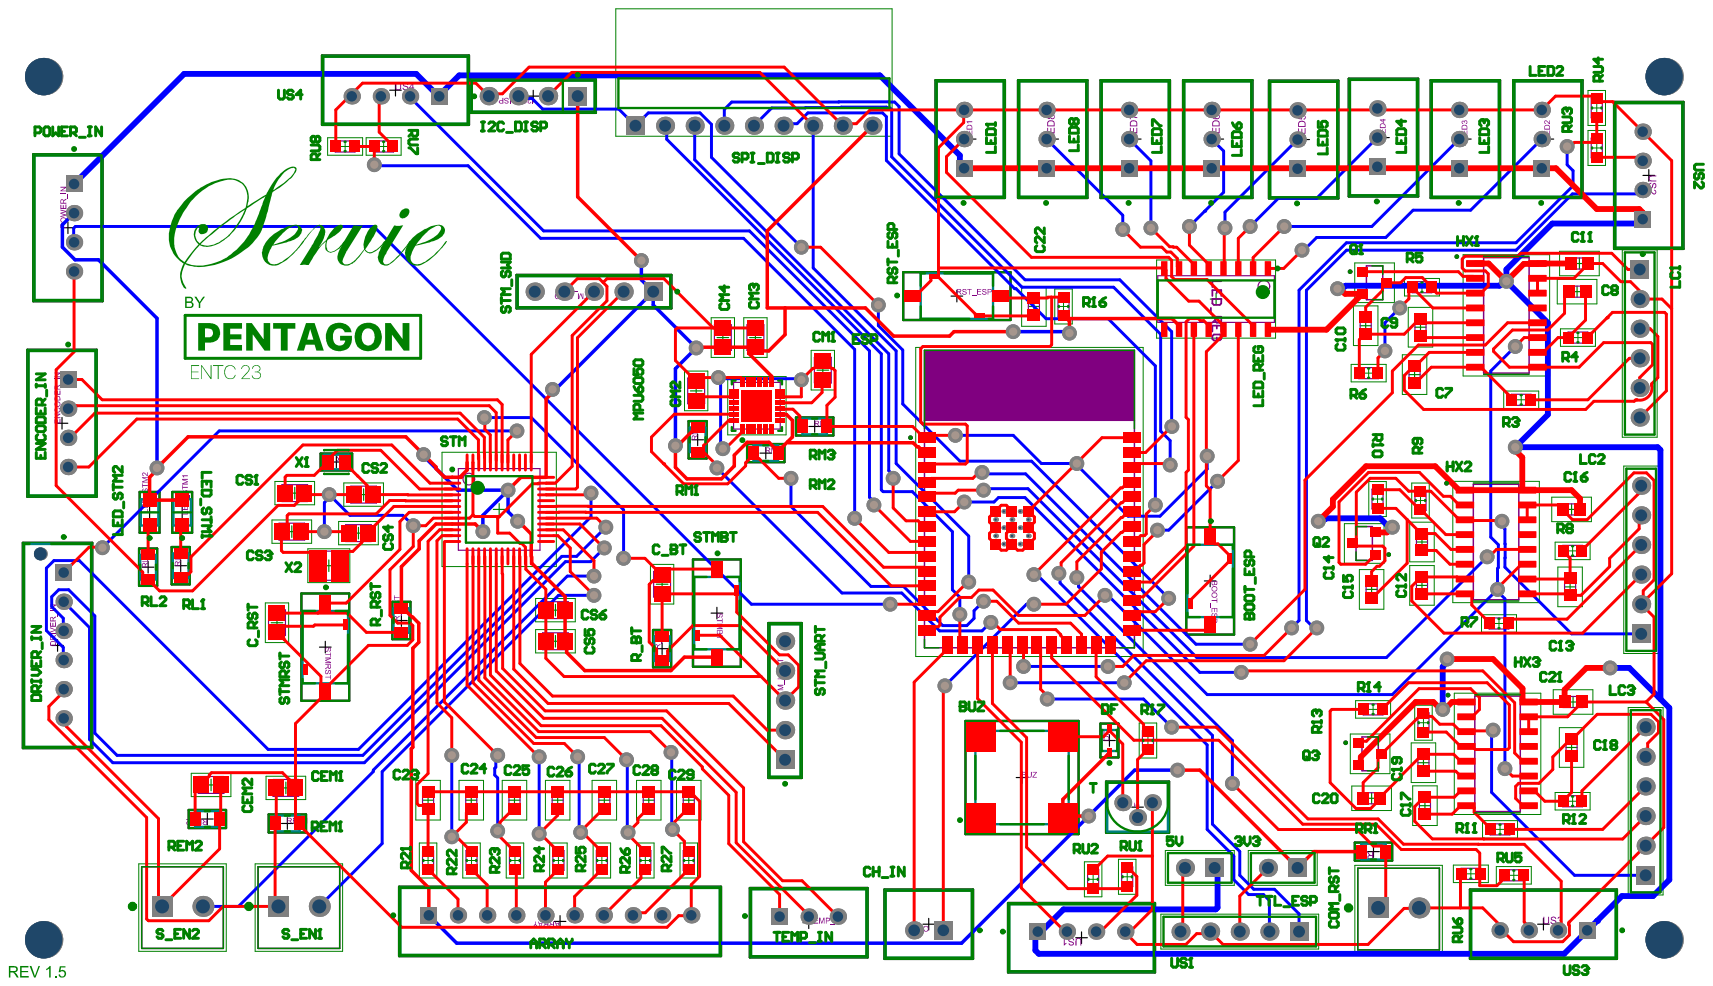
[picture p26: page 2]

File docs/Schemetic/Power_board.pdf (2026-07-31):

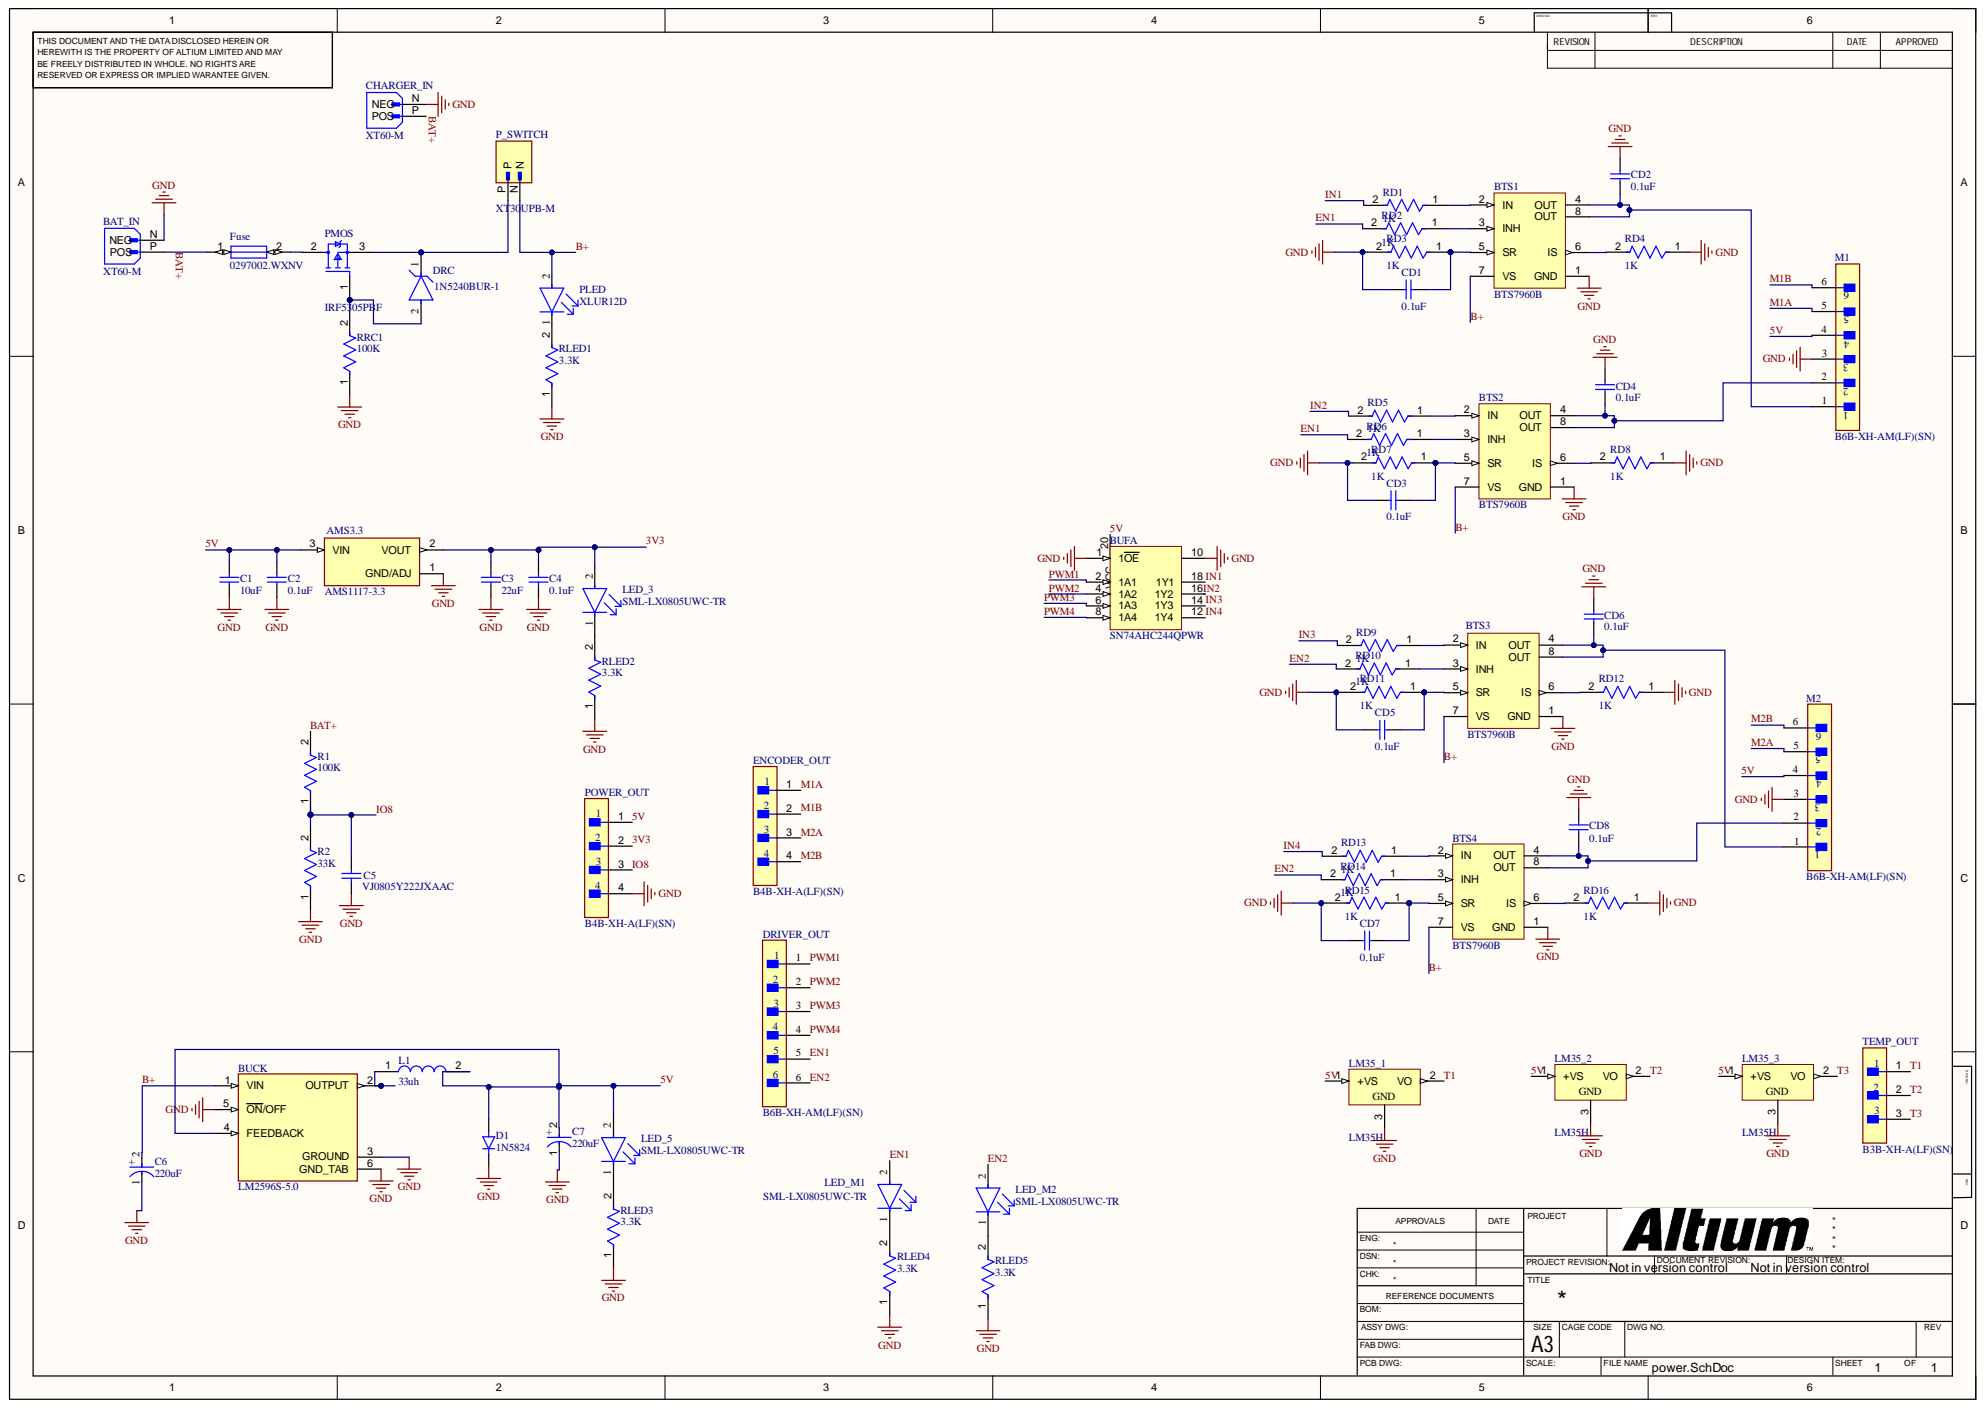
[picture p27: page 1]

1 | 2 | 3 | 4 | 5 | DWG NO: | REV: | 6

THIS DOCUMENT AND THE DATA DISCLOSED HEREIN OR HEREWITH IS THE PROPERTY OF ALTIUM LIMITED AND MAY BE FREELY DISTRIBUTED IN WHOLE. NO RIGHTS ARE RESERVED OR EXPRESS OR IMPLIED WARANTEE GIVEN. | P_SWITCH | REVISION | DESCRIPTION | DATE | APPROVED

DATE | PROJECT | * * APPROVALS * *

ENG: *
CHK: * | | TITLE *

DSN: * | | PROJECT REVISION: Not in version control | DOCUMENT REVISION: Not in version control | DESIGN ITEM:

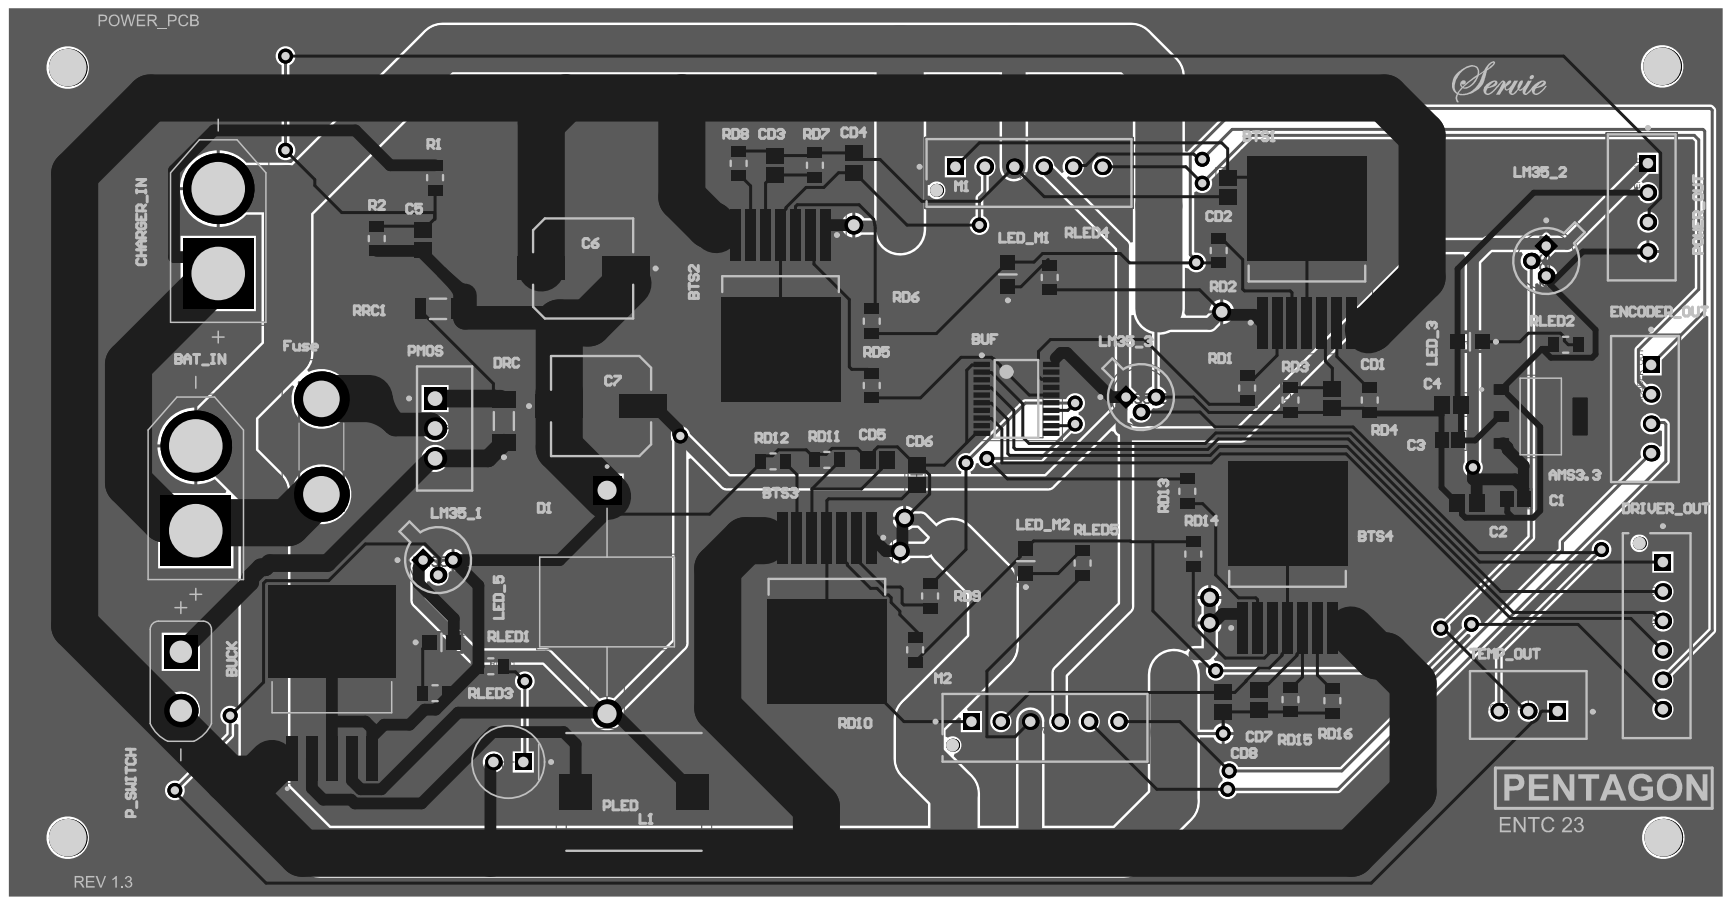
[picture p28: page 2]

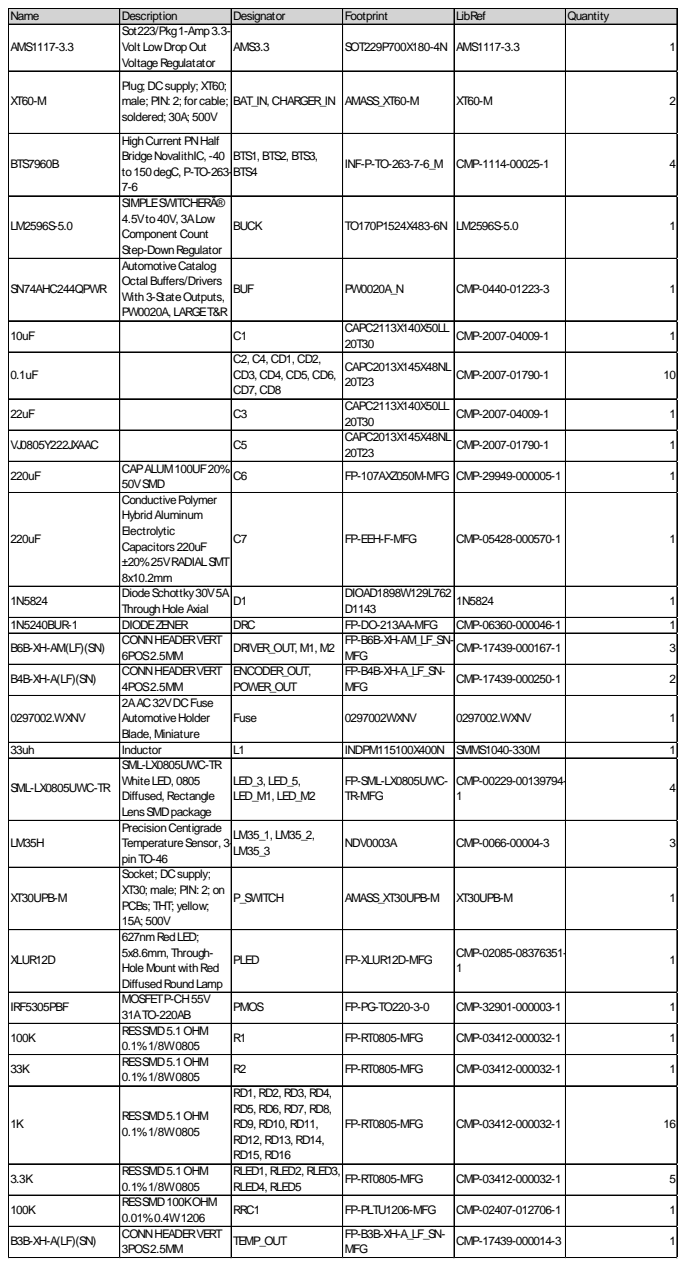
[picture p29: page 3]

Name | Description | Designator | Footprint | LibRef | Quantity
AMS1117-3.3 | Sot223/Pkg1-Amp3.3-Volt LowDropOut VoltageRegulatator | AMS3.3 | SOT229P700X180-4N | AMS1117-3.3 | 1

XT60-M | Plug; DCsupply; XT60; male; PIN: 2; for cable; soldered; 30A; 500V | BAT_IN, CHARGER_IN | AMASS_XT60-M | XT60-M | 2

BTS7960B | HighCurrent PNHalf BridgeNovalithIC, -40 to150degC, P-TO-263-7-6 | BTS1, BTS2, BTS3, BTS4 | INF-P-TO-263-7-6_M | CMP-1114-00025-1 | 4

LM2596S-5.0 | SIMPLESWITCHERÂ® 4.5Vto40V, 3ALow Component Count Step-DownRegulator | BUCK | TO170P1524X483-6N | LM2596S-5.0 | 1

SN74AHC244QPWR | AutomotiveCatalog Octal Buffers/Drivers With3-StateOutputs, PW0020A, LARGET&R | BUF | PW0020A_N | CMP-0440-01223-3 | 1

10uF | | C1 | CAPC2113X140X50LL 20T30 | CMP-2007-04009-1 | 1

0.1uF | | C2, C4, CD1, CD2, CD3, CD4, CD5, CD6, CD7, CD8 | CAPC2013X145X48NL 20T23 | CMP-2007-01790-1 | 10

22uF | | C3 | CAPC2113X140X50LL 20T30 | CMP-2007-04009-1 | 1

VJ0805Y222JXAAC | | C5 | CAPC2013X145X48NL 20T23 | CMP-2007-01790-1 | 1

220uF | CAPALUM100UF20% 50VSMD | C6 | FP-107AXZ050M-MFG | CMP-29949-000005-1 | 1

220uF | ConductivePolymer HybridAluminum Electrolytic Capacitors220uF ±20%25VRADIALSMT 8x10.2mm | C7 | FP-EEH-F-MFG | CMP-05428-000570-1 | 1

1N5824 | DiodeSchottky30V5A ThroughHoleAxial | D1 | DIOAD1898W129L762 D1143 | 1N5824 | 1

1N5240BUR-1 | DIODEZENER | DRC | FP-DO-213AA-MFG | CMP-06360-000046-1 | 1
B6B-XH-AM(LF)(SN) | CONNHEADERVERT 6POS2.5MM | DRIVER_OUT, M1, M2 | FP-B6B-XH-AM_LF_SN-MFG | CMP-17439-000167-1 | 3

B4B-XH-A(LF)(SN) | CONNHEADERVERT 4POS2.5MM | ENCODER_OUT, POWER_OUT | FP-B4B-XH-A_LF_SN-MFG | CMP-17439-000250-1 | 2

0297002.WXNV | 2AAC32VDCFuse AutomotiveHolder Blade, Miniature | Fuse | 0297002WXNV | 0297002.WXNV | 1

33uh | Inductor | L1 | INDPM115100X400N | SMMS1040-330M | 1
SML-LX0805UWC-TR | SML-LX0805UWC-TR WhiteLED, 0805 Diffused, Rectangle LensSMDpackage | LED_3, LED_5, LED_M1, LED_M2 | FP-SML-LX0805UWC-TR-MFG | CMP-00229-00139794-1 | 4

LM35H | PrecisionCentigrade TemperatureSensor, 3-pin TO-46 | LM35_1, LM35_2, LM35_3 | NDV0003A | CMP-0066-00004-3 | 3

XT30UPB-M | Socket; DCsupply; XT30; male; PIN: 2; on PCBs; THT; yellow; 15A; 500V | P_SWITCH | AMASS_XT30UPB-M | XT30UPB-M | 1

XLUR12D | 627nmRedLED; 5x8.6mm, Through-Hole Mount withRed DiffusedRoundLamp | PLED | FP-XLUR12D-MFG | CMP-02085-08376351-1 | 1

IRF5305PBF | MOSFETP-CH55V 31ATO-220AB | PMOS | FP-PG-TO220-3-0 | CMP-32901-000003-1 | 1

100K | RESSMD5.1OHM 0.1%1/8W0805 | R1 | FP-RT0805-MFG | CMP-03412-000032-1 | 1

33K | RESSMD5.1OHM 0.1%1/8W0805 | R2 | FP-RT0805-MFG | CMP-03412-000032-1 | 1

1K | RESSMD5.1OHM 0.1%1/8W0805 | RD1, RD2, RD3, RD4, RD5, RD6, RD7, RD8, RD9, RD10, RD11, RD12, RD13, RD14, RD15, RD16 | FP-RT0805-MFG | CMP-03412-000032-1 | 16

3.3K | RESSMD5.1OHM 0.1%1/8W0805 | RLED1, RLED2, RLED3, RLED4, RLED5 | FP-RT0805-MFG | CMP-03412-000032-1 | 5

100K | RESSMD100KOHM 0.01%0.4W1206 | RRC1 | FP-PLTU1206-MFG | CMP-02407-012706-1 | 1

B3B-XH-A(LF)(SN) | CONNHEADERVERT 3POS2.5MM | TEMP_OUT | FP-B3B-XH-A_LF_SN-MFG | CMP-17439-000014-3 | 1

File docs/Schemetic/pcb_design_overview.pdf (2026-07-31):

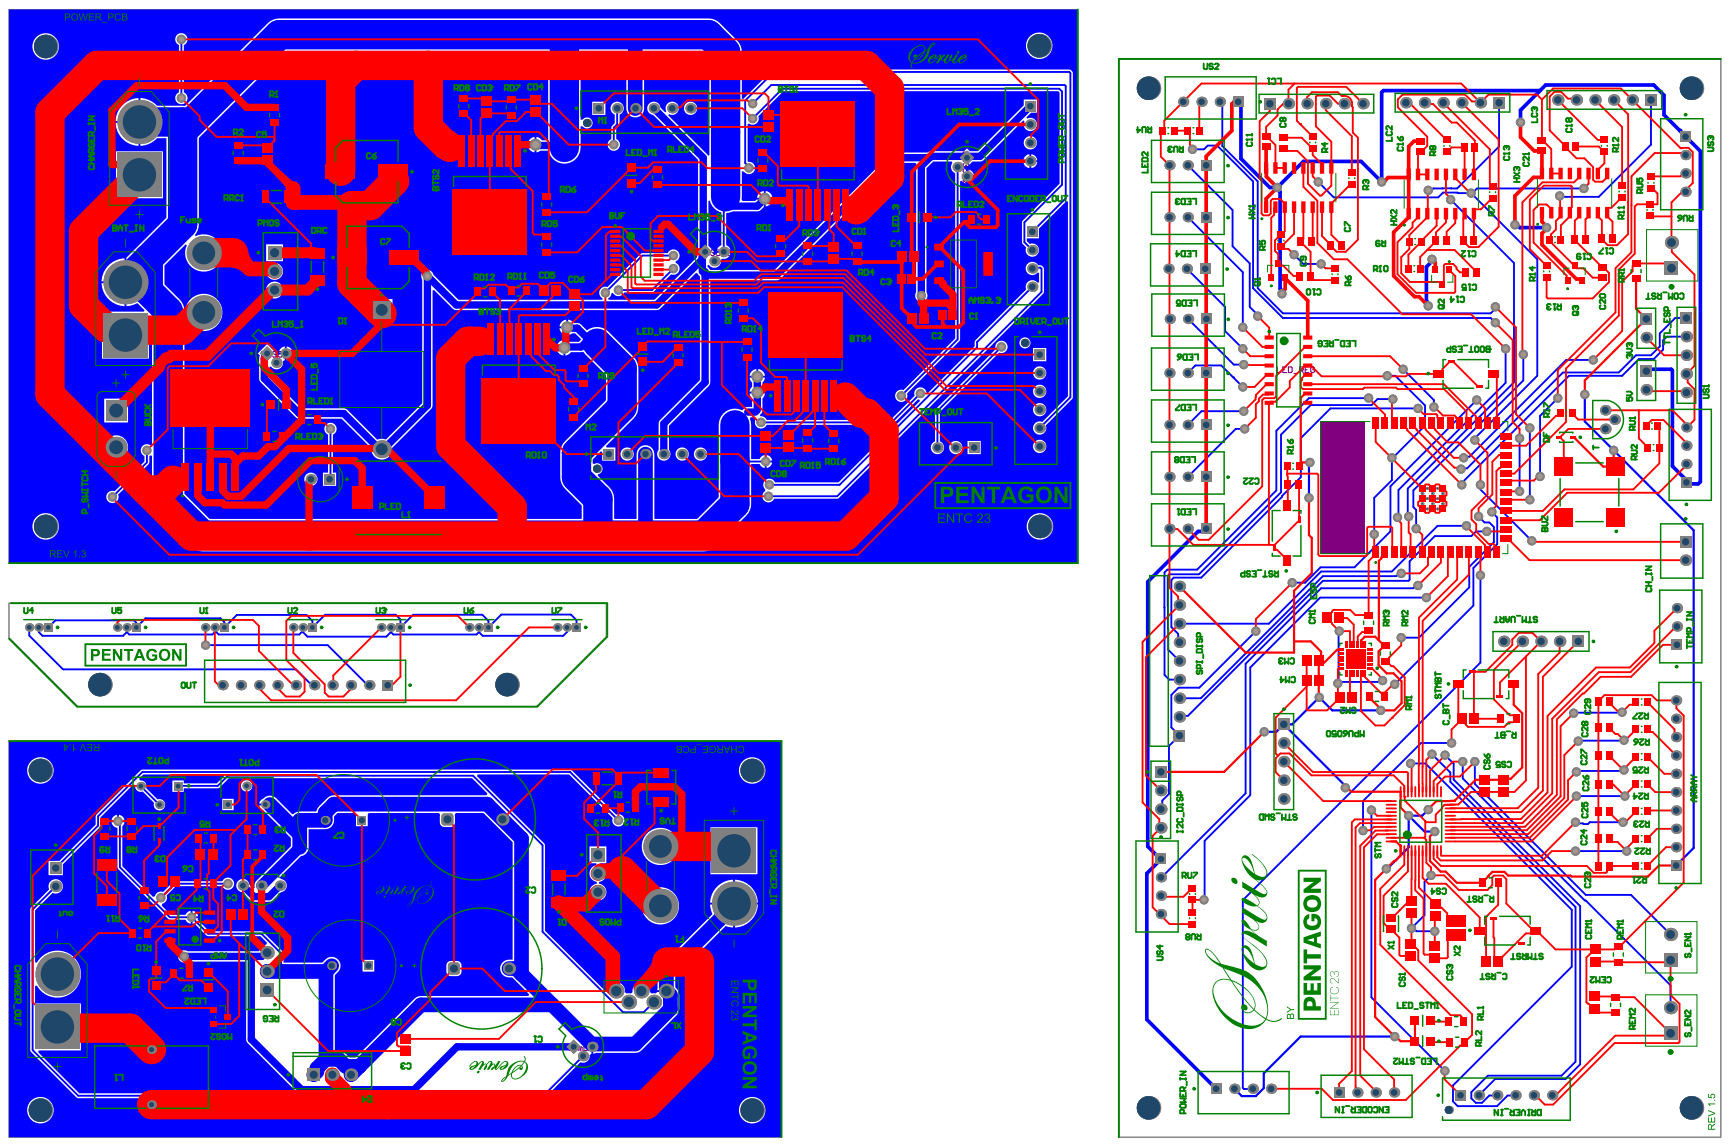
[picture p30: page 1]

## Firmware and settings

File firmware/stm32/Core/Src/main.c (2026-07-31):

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

#include "main.h"

/* USER CODE BEGIN Includes */
#include <stdio.h>
#include <string.h>
#include <stdlib.h>
#include <stdint.h>
/* USER CODE END Includes */

ADC_HandleTypeDef hadc1;
UART_HandleTypeDef huart1;   /* USART1: STM32 <-> ESP32 */
UART_HandleTypeDef huart3;   /* USART3: debug serial */
TIM_HandleTypeDef htim4;

void SystemClock_Config(void);
static void MX_GPIO_Init(void);
static void MX_ADC1_Init(void);
static void MX_USART1_UART_Init(void);
static void MX_USART3_UART_Init(void);
static void MX_TIM4_Init(void);

/* USER CODE BEGIN PFP */
uint16_t Read_ADC_Channel(uint32_t channel);
void Read_All_Hall_Sensors(void);
int Calculate_Line_Error(int *errorOut, int *strengthOut);
int Detect_T_Junction(void);
int Detect_Stop_Cross_Marker(void);
int Detect_Clear_90_Joint(void);

typedef enum
{
  ROUTE_CMD_STRAIGHT = 0,
  ROUTE_CMD_LEFT,
  ROUTE_CMD_RIGHT,
  ROUTE_CMD_STOP,       /* same behavior as serve stop in this version */
  ROUTE_CMD_SERVE_STOP = ROUTE_CMD_STOP,
  ROUTE_CMD_DOCK
} RouteCommand;

RouteCommand GetCurrentRouteCommand(void);
uint8_t IsJunctionRouteCommand(RouteCommand cmd);
uint8_t IsStrongRouteJunctionCandidate(int tDetected, int stopCrossDetected, int clear90Detected);
void ClearTurnHoldState(void);
void ResetPidFiltersFromError(int error);
void StartRouteJunctionStop(int8_t direction);
void StartRouteTurn(int8_t direction);
void FinishRouteTurn(int error);
void StartRouteStraightPass(void);
uint8_t BuildReturnRouteFromCurrentPosition(void);
uint8_t StartImmediateReturnToDock(void);
void StartServeStopSequence(void);
void StartDockStopTurnSequence(void);
void StartDockReverseToT(void);
void FinishDockParking(void);
uint8_t IsUTurnLineLocked(int lineDetected, int tDetected, int error);
uint8_t UpdateWideMarkerDetection(int tDetected);
uint8_t UpdateStopCrossMarkerDetection(int crossDetected);

void SetRobotSpeed(int leftSpeed, int rightSpeed);
void SetRobotSpeedSmooth(int leftSpeed, int rightSpeed, int step);
void DriveLeftMotor(int speed);
void DriveRightMotor(int speed);
void MotorStop(void);
void ResetFollowStateAfterStop(void);

void UpdateEncoders(void);
void Print_Debug(int error, int strength, int leftSpeed, int rightSpeed, int lineDetected);

/* ESP32 command UART helpers */
void CheckEspCommand(void);
void ProcessEspCommand(char *line);
uint8_t LoadRouteFromCsv(char *csv);
void ResetRouteRuntimeState(void);
void EspSendText(const char *text);
void EspSendEvent(const char *eventName);
void UpdateTimedRouteEvents(void);
uint8_t DetectDestinationTableFromRoute(void);
void ReportRouteJunctionEvent(void);
void ReportRouteTableEvent(void);
void SendHallSnapshot(const char *prefix);

int clamp_int(int value, int minVal, int maxVal);
int move_towards_int(int current, int target, int step);
/* USER CODE END PFP */

/* USER CODE BEGIN 0 */

/* ============================================================
   HALL SENSOR SETUP

   ADC pins:
   H0 = PA0
   H1 = PA1
   H2 = PA2
   H3 = PA3
   H4 = PA4
   H5 = PA5
   H6 = PA6

   Physical order:
   Left to right:
   L0 = H6
   L1 = H5
   L2 = H2
   L3 = H1
   L4 = H0
   L5 = H4
   L6 = H3

   Error convention:
   Left side  = negative
   Center     = 0
   Right side = positive
   ============================================================ */

uint32_t hallChannels[7] = {
  ADC_CHANNEL_0,
  ADC_CHANNEL_1,
  ADC_CHANNEL_2,
  ADC_CHANNEL_3,
  ADC_CHANNEL_4,
  ADC_CHANNEL_5,
  ADC_CHANNEL_6
};

uint16_t hallRaw[7];

uint16_t hallBaseline[7] = {
  2050,  // H0
  2047,  // H1
  2037,  // H2
  2115,  // H3
  2080,  // H4
  2082,  // H5
  2075   // H6
};

uint8_t physicalOrder[7] = {
  6, 5, 2, 1, 0, 4, 3
};

int weights[7] = {
  -300, -200, -100, 0, 100, 200, 300
};

/* Hall detection */
#define MAG_THRESHOLD       35
#define MIN_LINE_STRENGTH   55

/* Temporarily disable broken H6 / L0 sensor only.
   No other line-following logic is changed. */
#define DISABLE_H6_SENSOR   0

/* JGB37 minimum drive */
#define MIN_DRIVE_SPEED     30

/* Wide marker / T-junction detection
   Because H6/L0 is disabled, active count 4 is used instead of 5.
   This is used only as a marker/junction event now.
   It is NOT used directly as an automatic stop. */
#define T_ACTIVE_COUNT      5
#define T_MIN_STRENGTH      260
#define T_CONFIRM_COUNT     3

uint8_t activePhysical[7] = {0};
int activeCount = 0;
int lastStrengthSum = 0;

/* kept name for debug compatibility; now means final route stop, not T-stop */
uint8_t stoppedAtTJunction = 0;
uint8_t tJunctionCounter = 0;

/* ============================================================
   ROUTE COMMAND SETUP

   Only this array is hardcoded for now.
   Later the ESP/frontend can fill routeCommands[] and routeCommandCount.

   Current evaluation map requested:
   Dock/start -> normal 30-degree segmented bends handled by PID
   -> decision junction / clear 90 joint -> STRAIGHT
   -> table T marker -> SERVE_STOP
   -> wait, reverse a little, 180 turn
   -> return path -> pass decision junction STRAIGHT
   -> dock T marker -> DOCK stop + 180 turn + final stop
   ============================================================ */

#define ROUTE_MAX_COMMANDS  10

RouteCommand routeCommands[ROUTE_MAX_COMMANDS] = {
  ROUTE_CMD_RIGHT,       /* first junction: take right path */
  ROUTE_CMD_STRAIGHT,    /* second junction: pass table 2 */
  ROUTE_CMD_SERVE_STOP,  /* table 3 T marker: stop, wait, reverse, 180 turn */
  ROUTE_CMD_STRAIGHT,    /* return: pass table 2 junction */
  ROUTE_CMD_LEFT,        /* return: turn back toward dock at first junction */
  ROUTE_CMD_DOCK         /* dock T marker */
};


uint8_t routeCommandCount = 0;  /* Filled by ESP32 ROUTE command */
uint8_t routeIndex = 0;
uint8_t routeFinished = 1;     /* Wait stopped until ESP32 sends a route */
uint8_t routePaused = 0;
uint8_t routeError = 0;
uint8_t routeJunctionDirectCounter = 0;
uint8_t executingRouteStartExit = 0;
uint32_t routeStartExitStartTime = 0;
uint32_t routeStartIgnoreUntil = 0;

/* Marker behavior */
#define STOP_MARKER_REQUIRED_CROSSES     1
#define MARKER_CLEAR_CONFIRM_COUNT       2
#define MARKER_COOLDOWN_MS               350
#define MARKER_IGNORE_AFTER_COMMAND_MS   1200
/*
   When a new route is received from ESP32, the robot may already be sitting
   on the dock/start T marker. If route detection is enabled immediately,
   that start marker can be mistaken as the first route junction and the robot
   will start turning at the dock.

   So after loading a route:
   - drive straight briefly to leave the dock marker
   - ignore route marker consumption for a little longer
*/
#define ROUTE_START_EXIT_MS              650  /* drive forward briefly to leave dock/start T */
#define ROUTE_START_MARKER_IGNORE_MS     1800
#define ROUTE_STRAIGHT_PASS_MS           800

/* STOP marker detection uses a stricter cross pattern than junction detection.
   This prevents a normal L/right-angle path turn from being counted as a stop marker. */
#define STOP_CROSS_ACTIVE_COUNT          5
#define STOP_CROSS_MIN_STRENGTH          340
#define STOP_CROSS_CONFIRM_COUNT         2
#define STOP_CROSS_CLEAR_CONFIRM_COUNT   2

/* Clear 90-degree / branch-joint detection.
   This is for bus-topology decision points seen from the head side, where
   the robot may see a side path before it can prove a full T.
   Gentle 30-degree segmented bends should not be shaped strongly enough to
   trigger this. */
#define CLEAR_90_MIN_STRENGTH            210
#define CLEAR_90_MIN_ACTIVE              3

/* Serve / dock sequence behavior */
/* Wait at table until ESP32 says FOOD_TAKEN, or timeout after 5 minutes. */
#define SERVE_WAIT_MS                    300000
#define SERVE_REVERSE_MS                 600
#define SERVE_REVERSE_SPEED              32
#define SERVE_UTURN_SPEED                30
#define SERVE_UTURN_MIN_MS               2200
#define SERVE_UTURN_MAX_MS               11000
#define SERVE_UTURN_DIRECTION            1    /* 1 or -1; change if it turns wrong way */

#define DOCK_STOP_WAIT_MS                350
/* Dock now uses the same stable method as the table serve turn:
   stop -> reverse a little -> 180 turn -> stop/settle -> reverse to T. */
#define DOCK_PRE_TURN_REVERSE_MS         SERVE_REVERSE_MS
#define DOCK_PRE_TURN_REVERSE_SPEED      SERVE_REVERSE_SPEED
#define DOCK_UTURN_SPEED                 SERVE_UTURN_SPEED
#define DOCK_UTURN_MIN_MS                SERVE_UTURN_MIN_MS
#define DOCK_UTURN_MAX_MS                SERVE_UTURN_MAX_MS
#define DOCK_UTURN_DIRECTION             SERVE_UTURN_DIRECTION
#define DOCK_AFTER_UTURN_SETTLE_MS       350  /* stop fully before reverse-to-T */
#define DOCK_REVERSE_SPEED               26   /* slow reverse after dock turn */
#define DOCK_REVERSE_MIN_MS              250  /* ignore very early T readings */
#define DOCK_REVERSE_MAX_MS              7000 /* safety timeout if T is not found */
#define DOCK_REVERSE_T_CONFIRM_COUNT     1

/* Dock parking reverse steering only.
   This is active only in DOCK_STATE_REVERSE_TO_T.
   It uses the front Hall array error while reversing so the robot can correct
   the small angle left after the dock 180-degree turn.

   If the robot corrects in the wrong direction during reverse parking, change
   DOCK_REVERSE_STEER_INVERT from 0 to 1. */
#define DOCK_REVERSE_STEER_ENABLE        1
#define DOCK_REVERSE_STEER_KP            0.07f
#define DOCK_REVERSE_STEER_MAX           10
#define DOCK_REVERSE_STEER_INVERT        0

#define UTURN_CENTER_CONFIRM_COUNT       3
#define UTURN_LOCK_ERROR                 115
#define UTURN_LOCK_MAX_ACTIVE            3

/* Commanded turn behavior at route junctions
   New method:
   - Stop immediately at a confirmed T/wide marker.
   - After a short pause, use the same gentle base-code turn recovery style
     that already works on normal path turns: one wheel moves forward, the
     other wheel is stopped. No reverse pivot and no fast circular turn. */
#define ROUTE_JUNCTION_STOP_MS           320
/* After stopping at the T, keep the commanded turn until the chosen
   branch is center-locked. Then release back to normal PID/turn-hold. */
#define ROUTE_TURN_MIN_MS                1400
#define ROUTE_TURN_MAX_MS                10500
#define ROUTE_TURN_CENTER_CONFIRM_COUNT  3
#define ROUTE_TURN_RAMP_STEP             RECOVERY_RAMP_STEP
#define ROUTE_TURN_SPEED                 RECOVERY_SPEED
#define ROUTE_AFTER_TURN_IGNORE_MS       0
#define ROUTE_BRANCH_LOCK_ERROR          115
#define ROUTE_BRANCH_LOCK_MAX_ACTIVE     3

/* Direct route-junction confirmation.
   The uploaded log showed W:1/SC:1 but RIdx stayed 0, so relying only
   on one wideMarkerEvent was not robust enough. This counter consumes
   LEFT/RIGHT/STRAIGHT as soon as a strong junction/cross is seen. */
#define ROUTE_JUNCTION_DIRECT_CONFIRM_COUNT 1

uint8_t wideMarkerActive = 0;
uint8_t wideMarkerClearCounter = 0;
uint32_t markerIgnoreUntil = 0;
uint32_t lastMarkerEventTime = 0;

uint8_t stopMarkerCount = 0;

uint8_t stopCrossActive = 0;
uint8_t stopCrossConfirmCounter = 0;
uint8_t stopCrossClearCounter = 0;
uint8_t lastStopCrossDetected = 0;

uint8_t executingRouteJunctionStop = 0;
int8_t routeJunctionStopDirection = 0;  // -1 = left, +1 = right
uint32_t routeJunctionStopStartTime = 0;

uint8_t executingRouteTurn = 0;
int8_t routeTurnDirection = 0;    // -1 = left, +1 = right
uint32_t routeTurnStartTime = 0;
uint8_t routeTurnCenterConfirmCount = 0;

uint8_t executingRouteStraight = 0;
uint32_t routeStraightStartTime = 0;

typedef enum
{
  SERVE_STATE_NONE = 0,
  SERVE_STATE_WAIT,
  SERVE_STATE_REVERSE,
  SERVE_STATE_UTURN
} ServeState;

typedef enum
{
  DOCK_STATE_NONE = 0,
  DOCK_STATE_WAIT,
  DOCK_STATE_PRE_TURN_REVERSE,
  DOCK_STATE_UTURN,
  DOCK_STATE_REVERSE_SETTLE,
  DOCK_STATE_REVERSE_TO_T
} DockState;

uint8_t serveSequenceActive = 0;
ServeState serveState = SERVE_STATE_NONE;
uint32_t serveStateStartTime = 0;
uint8_t serveUturnCenterConfirmCount = 0;
uint8_t serveFoodTakenReleased = 0;

uint8_t dockSequenceActive = 0;
DockState dockState = DOCK_STATE_NONE;
uint32_t dockStateStartTime = 0;
uint8_t dockUturnCenterConfirmCount = 0;
uint8_t dockReverseTConfirmCount = 0;

/* ============================================================
   MOTOR SETUP

   Right motor = Motor 1:
   PB6 = TIM4_CH1 = Right motor IN1 / RPWM
   PB7 = TIM4_CH2 = Right motor IN2 / LPWM
   PB13 = Right motor EN

   Left motor = Motor 2:
   PB8 = TIM4_CH3 = Left motor IN1 / RPWM
   PB9 = TIM4_CH4 = Left motor IN2 / LPWM
   PB14 = Left motor EN
   ============================================================ */

#define PWM_MAX_COUNT 399

#define RIGHT_MOTOR_INVERT 0
#define LEFT_MOTOR_INVERT  1

#define RIGHT_EN_GPIO_Port GPIOB
#define RIGHT_EN_Pin       GPIO_PIN_13

#define LEFT_EN_GPIO_Port  GPIOB
#define LEFT_EN_Pin        GPIO_PIN_14

/* ============================================================
   SOFTWARE ENCODERS

   Right motor encoder:
   A = PB5
   B = PB15

   Left motor encoder:
   A = PA8
   B = PA12
   ============================================================ */

volatile int32_t rightEncoderCount = 0;
volatile int32_t leftEncoderCount  = 0;

uint8_t lastRightEncA = 0;
uint8_t lastLeftEncA  = 0;

/* ============================================================
   PID SETTINGS FOR JGB37

   If correction is still slow, increase Kp slightly.
   If it shakes left/right, reduce Kd or Kp slightly.
   ============================================================ */

float Kp = 0.068f;
float Ki = 0.00f;
float Kd = 0.016f;

float integral = 0.0f;
float lastError = 0.0f;
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
int main(void)
{
  HAL_Init();

  SystemClock_Config();

  MX_GPIO_Init();
  MX_ADC1_Init();
  MX_USART1_UART_Init();
  MX_USART3_UART_Init();
  MX_TIM4_Init();

  /* USER CODE BEGIN 2 */

  HAL_ADCEx_Calibration_Start(&hadc1);

  HAL_TIM_PWM_Start(&htim4, TIM_CHANNEL_1);
  HAL_TIM_PWM_Start(&htim4, TIM_CHANNEL_2);
  HAL_TIM_PWM_Start(&htim4, TIM_CHANNEL_3);
  HAL_TIM_PWM_Start(&htim4, TIM_CHANNEL_4);

  MotorStop();

  lastRightEncA = HAL_GPIO_ReadPin(GPIOB, GPIO_PIN_5);
  lastLeftEncA  = HAL_GPIO_ReadPin(GPIOA, GPIO_PIN_8);

  char startMsg[] =
      "\r\nLine follower PID started - JGB37 table1 serve-return-dock version\r\n"
      "Right motor: PB6/PB7, encoder PB5/PB15\r\n"
      "Left motor : PB8/PB9, encoder PA8/PA12\r\n"
      "Waiting for ESP32 route command on USART1 PA9/PA10.\r\n"
      "After receiving route, robot moves forward briefly; start markers are ignored.\r\n"
      "Normal 30-degree bends are PID only; T/clear-90 joints consume commands.\r\n"
      "SERVE_STOP: wait, reverse little, 180 turn, then return.\r\n"
      "DOCK: T/cross/clear-90 marker starts dock sequence, then turn and reverse until same T is detected.\r\n";

  HAL_UART_Transmit(&huart3, (uint8_t*)startMsg, strlen(startMsg), 200);

  EspSendText("STM32_READY\n");

  /* USER CODE END 2 */

  while (1)
  {
    uint32_t loopStart = HAL_GetTick();

    CheckEspCommand();

    int error = 0;
    int strength = 0;
    int leftSpeed = 0;
    int rightSpeed = 0;

    UpdateEncoders();
    Read_All_Hall_Sensors();

    int lineDetected = Calculate_Line_Error(&error, &strength);
    int tDetected = Detect_T_Junction();
    int stopCrossDetected = Detect_Stop_Cross_Marker();
    int clear90Detected = Detect_Clear_90_Joint();
    uint8_t wideMarkerEvent = UpdateWideMarkerDetection(tDetected);
    uint8_t stopCrossEvent = UpdateStopCrossMarkerDetection(stopCrossDetected);
    uint8_t routeStartMarkerIgnoreActive = (!routeFinished && !routeError &&
                                            HAL_GetTick() < routeStartIgnoreUntil);

    UpdateTimedRouteEvents();
    if (routePaused)
    {
      MotorStop();

      if (HAL_GetTick() - lastDebugPrint >= 200)
      {
        Print_Debug(error, strength, 0, 0, lineDetected);
        lastDebugPrint = HAL_GetTick();
      }

      while ((HAL_GetTick() - loopStart) < 20)
      {
        UpdateEncoders();
        CheckEspCommand();
      }

      continue;
    }


    /* ========================================================
       ROUTE COMMAND EVENT HANDLING

       Logic is generic:
       - LEFT/RIGHT/STRAIGHT commands are consumed only at a T/wide/clear-90 decision point.
       - SERVE_STOP stops at the first table T/cross marker, waits, reverses, and turns.
       - DOCK stops at the dock T/cross marker, turns, and finishes.
       - Normal 30-degree segmented bends do not consume commands; PID handles them.
       ======================================================== */

    if (!stoppedAtTJunction && !routeFinished && !routeError && !routeStartMarkerIgnoreActive)
    {
      RouteCommand cmd = GetCurrentRouteCommand();
      uint8_t strongJunctionCandidate = IsStrongRouteJunctionCandidate(tDetected, stopCrossDetected, clear90Detected);

      /*
        LEFT / RIGHT / STRAIGHT are consumed at a strong wide/T/cross pattern.

        Important fix:
        The log showed W:1 and SC:1 while RIdx stayed 0. That meant the first
        LEFT command was never consumed, so the final stop marker was still
        interpreted while Cmd was LEFT instead of STOP.

        Therefore route-junction commands no longer depend only on a single
        wideMarkerEvent pulse. A strong direct candidate is enough after this
        small confirmation counter.
      */
      if (IsJunctionRouteCommand(cmd) &&
          !executingRouteJunctionStop && !executingRouteTurn && !executingRouteStraight &&
          !serveSequenceActive && !dockSequenceActive)
      {
        if (wideMarkerEvent || strongJunctionCandidate)
        {
          if (routeJunctionDirectCounter < 255)
          {
            routeJunctionDirectCounter++;
          }
        }
        else
        {
          routeJunctionDirectCounter = 0;
        }

        if (wideMarkerEvent || routeJunctionDirectCounter >= ROUTE_JUNCTION_DIRECT_CONFIRM_COUNT)
        {
          routeJunctionDirectCounter = 0;

          if (cmd == ROUTE_CMD_LEFT)
          {
            if (routeIndex < routeCommandCount) routeIndex++;
            ReportRouteJunctionEvent();
            StartRouteJunctionStop(-1);
          }
          else if (cmd == ROUTE_CMD_RIGHT)
          {
            if (routeIndex < routeCommandCount) routeIndex++;
            ReportRouteJunctionEvent();
            StartRouteJunctionStop(1);
          }
          else if (cmd == ROUTE_CMD_STRAIGHT)
          {
            if (routeIndex < routeCommandCount) routeIndex++;
            ReportRouteJunctionEvent();
            StartRouteStraightPass();
          }
        }
      }
      else
      {
        routeJunctionDirectCounter = 0;
      }

      uint8_t confirmedStopMarker = 0;

      if (wideMarkerEvent || stopCrossEvent ||
          (tDetected && tJunctionCounter >= T_CONFIRM_COUNT) ||
          (stopCrossDetected && stopCrossConfirmCounter >= STOP_CROSS_CONFIRM_COUNT))
      {
        confirmedStopMarker = 1;
      }

      if (cmd == ROUTE_CMD_SERVE_STOP && confirmedStopMarker &&
          !executingRouteJunctionStop && !executingRouteTurn && !executingRouteStraight &&
          !serveSequenceActive && !dockSequenceActive)
      {
        if (routeIndex < routeCommandCount) routeIndex++;
        stopMarkerCount = 1;
        ReportRouteTableEvent();
        StartServeStopSequence();
      }

      /*
        Dock can be seen differently depending on approach angle.
        In the latest log the robot reached the dock with RIdx:3 Cmd:4,
        but the dock marker appeared only as CJ:1 / clear-90 for a short time,
        not as a fully confirmed W/SC marker. Because DOCK ignored CJ, normal
        turn-hold took over and the robot pivoted around one tire.

        So DOCK accepts a clear 90 / branch-joint candidate directly.
        This is only for DOCK; SERVE_STOP still uses the stricter T/cross marker.
      */
      uint8_t confirmedDockMarker = confirmedStopMarker;
      if (cmd == ROUTE_CMD_DOCK && clear90Detected)
      {
        confirmedDockMarker = 1;
      }

      if (cmd == ROUTE_CMD_DOCK && confirmedDockMarker &&
          !executingRouteJunctionStop && !executingRouteTurn && !executingRouteStraight &&
          !serveSequenceActive && !dockSequenceActive)
      {
        stopMarkerCount = 1;
        EspSendEvent("DOCK_MARKER");
        StartDockStopTurnSequence();
      }
    }

    /*
      As soon as a T/wide marker is seen and the next command is a junction
      command, hold the robot stopped while the marker is being confirmed.
      This avoids the earlier problem where a tilted robot entered the right
      branch before the LEFT route command was applied.
    */
    uint8_t routeJunctionCandidate = 0;
    uint8_t routeStopCandidate = 0;

    if (!stoppedAtTJunction && !routeFinished && !routeError && !routeStartMarkerIgnoreActive &&
        !executingRouteJunctionStop && !executingRouteTurn && !executingRouteStraight &&
        !serveSequenceActive && !dockSequenceActive &&
        IsJunctionRouteCommand(GetCurrentRouteCommand()) &&
        (tDetected || stopCrossDetected || clear90Detected || tJunctionCounter > 0 || routeJunctionDirectCounter > 0))
    {
      routeJunctionCandidate = 1;
    }

    /*
      When the next command is STOP and the strict cross pattern is being seen,
      hold the motors stopped while the cross is being confirmed. Without this,
      normal turn-hold can rotate away from the stop mark before X increments.
    */
    if (!stoppedAtTJunction && !routeFinished && !routeError && !routeStartMarkerIgnoreActive &&
        !executingRouteJunctionStop && !executingRouteTurn && !executingRouteStraight &&
        (GetCurrentRouteCommand() == ROUTE_CMD_SERVE_STOP || GetCurrentRouteCommand() == ROUTE_CMD_DOCK) &&
        (tDetected || stopCrossDetected || tJunctionCounter > 0 || stopCrossConfirmCounter > 0 ||
         (GetCurrentRouteCommand() == ROUTE_CMD_DOCK && clear90Detected)))
    {
      routeStopCandidate = 1;
    }
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

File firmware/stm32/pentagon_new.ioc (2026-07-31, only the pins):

Mcu.UserName=STM32F103C8Tx
PA0-WKUP.Signal=ADCx_IN0
PA1.Signal=ADCx_IN1
PA10.Signal=USART1_RX
PA12.Signal=GPIO_Input
PA13.Signal=SYS_JTMS-SWDIO
PA14.Signal=SYS_JTCK-SWCLK
PA2.Signal=ADCx_IN2
PA3.Signal=ADCx_IN3
PA4.Signal=ADCx_IN4
PA5.Signal=ADCx_IN5
PA6.Signal=ADCx_IN6
PA8.Signal=GPIO_Input
PA9.Signal=USART1_TX
PB10.Signal=USART3_TX
PB11.Signal=USART3_RX
PB13.Signal=GPIO_Output
PB14.Signal=GPIO_Output
PB15.Signal=GPIO_Input
PB5.Signal=GPIO_Input
PB6.Signal=S_TIM4_CH1
PB7.Signal=S_TIM4_CH2
PB8.Signal=S_TIM4_CH3
PB9.Signal=S_TIM4_CH4

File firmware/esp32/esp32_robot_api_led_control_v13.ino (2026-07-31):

/*
  ESP32 API-only robot controller for local React web app
  -------------------------------------------------------
  This version does NOT host the full UI.
  It only hosts:
  - AP mode page
  - API endpoints for the React app

  Local React app on laptop calls:
  GET http://192.168.4.1/api/status
  GET http://192.168.4.1/api/serve?table=2
  GET http://192.168.4.1/api/stop

  Wiring:
  ESP32 IO17 TX  -> STM32 PA10 RX
  ESP32 IO18 RX  <- STM32 PA9 TX
  ESP32 GND      <-> STM32 GND

  UART route format sent to STM32:
  ROUTE:2,0,3,0,1,4\n

  STM32 command values:
  0 = STRAIGHT
  1 = LEFT
  2 = RIGHT
  3 = SERVE_STOP
  4 = DOCK
*/

#include <WiFi.h>
#include <WebServer.h>
#include <Preferences.h>
#include <ESPmDNS.h>
#include "HX711.h"
#include <Adafruit_NeoPixel.h>
#include <math.h>

#define ESP_UART_RX_PIN 18
#define ESP_UART_TX_PIN 17
#define STM_BAUD        115200

#define AP_SSID         "RestaurantRobot_AP"
#define AP_PASSWORD     "12345678"

IPAddress apLocalIp(192, 168, 4, 1);
IPAddress apGateway(192, 168, 4, 1);
IPAddress apSubnet(255, 255, 255, 0);

HardwareSerial STM32Serial(1);
WebServer server(80);
Preferences prefs;

String wifiSsid = "";
String wifiPass = "";
String lastRoute = "None";
String lastReply = "--";
String robotState = "Ready";
String selectedTable = "None";
unsigned long lastCommandTime = 0;

/* Tray-1 HX711 weight sensor + API calibration */
#define HX711_DOUT  5
#define HX711_SCK   20
#define FOOD_THRESHOLD_G 300.0f
#define FOOD_CLEAR_CONFIRM_COUNT 4   // kept for old status/debug compatibility
#define FOOD_EMPTY_CONFIRM_MS 10000UL  // food must stay below threshold for 10 seconds before return
#define WEIGHT_READ_INTERVAL_MS 500

#define BUZZER_PIN 48
#define FOOD_ALERT_INTERVAL_MS 5000
#define FOOD_ALERT_TONE_HZ 2200
#define FOOD_ALERT_TONE_MS 140

/* Ultrasonic obstacle sensors */
#define FRONT_TRIG_PIN 15
#define FRONT_ECHO_PIN 16
#define LEFT_TRIG_PIN  13
#define LEFT_ECHO_PIN  14
#define RIGHT_TRIG_PIN 11
#define RIGHT_ECHO_PIN 12

#define FRONT_OBSTACLE_CM 15.0f
#define SIDE_CLOSE_CM 28.0f
#define SIDE_FAST_APPROACH_DELTA_CM 5.0f
#define OBSTACLE_MIN_STOP_MS 5000
#define OBSTACLE_CLEAR_CONFIRM_MS 1200
#define OBSTACLE_HELP_MS 20000
#define OBSTACLE_ALERT_INTERVAL_MS 700

/* Power / dock sensing
   IO41: charger/pogo detector. Your measured values: connected ~= 3.0 V, not connected ~= 1.4 V.
   IO8 : battery divider ADC. Your measured values: 11.4 V battery -> 2.82 V at IO8.
*/
#define CHARGER_DETECT_PIN 41
#define BATTERY_ADC_PIN    8

#define CHARGER_CONNECTED_THRESHOLD_V 2.20f
#define POWER_READ_INTERVAL_MS        500UL

#define BATTERY_DIVIDER_FACTOR        (11.4f / 2.82f)  // ~= 4.043
#define BATTERY_FULL_V                12.50f
#define BATTERY_LOW_V                 10.50f

/* Software-only battery stabilizer.
   This does not fix the electrical noise, but it prevents the web app from
   jumping between false values like 100% and 4%.

   Method:
   1) Take many ADC samples and use the median.
   2) Keep a rolling median history.
   3) Ignore impossible jumps.
   4) When not charging, voltage is allowed to fall faster than rise.
      When charging, voltage is allowed to rise faster than fall.
*/
#define BATTERY_ADC_SAMPLES           31
#define BATTERY_HISTORY_COUNT         15
#define BATTERY_MIN_VALID_PACK_V      9.00f
#define BATTERY_MAX_VALID_PACK_V      13.20f
#define BATTERY_SPIKE_REJECT_V        0.85f
#define BATTERY_NOT_CHG_RISE_STEP_V   0.004f
#define BATTERY_NOT_CHG_FALL_STEP_V   0.025f
#define BATTERY_CHG_RISE_STEP_V       0.025f
#define BATTERY_CHG_FALL_STEP_V       0.004f


/* WS2812B decoration LEDs
   GPIO36 has one chained strip: first 88 LEDs = right side, next 88 LEDs = left side.
   GPIO37 is an optional extra decoration channel. If not connected, it is harmless.
   Install Arduino library: Adafruit NeoPixel.
*/
#define LED_PIN_36                36
#define LED_PIN_37                37
#define LED_SIDE_COUNT            88
#define LED36_RIGHT_START         0
#define LED36_LEFT_START          LED_SIDE_COUNT
#define LED36_TOTAL_COUNT         (LED_SIDE_COUNT * 2)
#define LED37_COUNT               88
#define LED_UPDATE_INTERVAL_MS    25UL

#define LED_PATTERN_FIXED         0
#define LED_PATTERN_RUNNING       1
#define LED_PATTERN_RANDOM        2
#define LED_PATTERN_RAINBOW       3
#define LED_PATTERN_BREATHING     4


HX711 trayScale;

/*
  HX711 library formula:
  weight_g = (raw_average - offset) / calibration_factor

  With your previous readings:
  empty raw ~= -530200
  1050g raw ~= -555600
  factor ~= (-555600 - -530200) / 1050 = -24.19
*/
float calibration_factor = -25.61f;
long trayOffsetRaw = 0;
bool trayOffsetSaved = false;
bool trayCalibrationSaved = false;

float trayWeightG = 0.0f;
long trayRawAverage = 0;
long trayValueRaw = 0;
bool trayReady = false;
bool trayHasFood = false;
bool servingWaitingForFood = false;
bool foodTakenSentThisServe = false;
uint8_t foodClearCounter = 0;
unsigned long foodEmptySinceMs = 0;
unsigned long lastWeightReadMs = 0;
unsigned long lastFoodAlertMs = 0;

float frontDistanceCm = -1;
float leftDistanceCm = -1;
float rightDistanceCm = -1;
float prevLeftDistanceCm = -1;
float prevRightDistanceCm = -1;

bool frontSensorEnabled = true;
bool leftSensorEnabled = true;
bool rightSensorEnabled = true;
uint32_t obstacleBypassUntilMs = 0;
bool obstaclePaused = false;
bool obstacleHelpNeeded = false;
String obstacleSensor = "none";
String obstacleMessage = "";
uint32_t obstacleStartMs = 0;
uint32_t obstacleClearStartMs = 0;
uint32_t lastObstacleAlertMs = 0;
uint32_t lastUltrasonicReadMs = 0;

int chargerAdcRaw = 0;
float chargerSenseVoltage = 0.0f;
bool chargerConnected = false;
uint8_t chargerConnectedCounter = 0;
uint8_t chargerDisconnectedCounter = 0;
bool chargerOnSentToSTM = false;

int batteryAdcRaw = 0;
float batteryPinVoltage = 0.0f;
float batteryVoltage = 0.0f;       // stable value used by the web app
float batteryVoltageRaw = 0.0f;    // latest raw/median ADC result before smart filtering
float batteryVoltageCandidate = 0.0f;
int batteryPercent = 0;
bool batteryLow = false;
bool batteryFilterReady = false;
bool batteryReadingUnstable = false;
uint8_t batteryLargeJumpCounter = 0;
uint8_t batteryHistoryIndex = 0;
uint8_t batteryHistoryCount = 0;
float batteryHistory[BATTERY_HISTORY_COUNT];
uint32_t lastPowerReadMs = 0;


struct LedRuntimeConfig
{
  bool enabled;
  uint8_t r;
  uint8_t g;
  uint8_t b;
  uint8_t brightness;
  uint8_t pattern;
  uint8_t speed;
};

Adafruit_NeoPixel ledStrip36(LED36_TOTAL_COUNT, LED_PIN_36, NEO_GRB + NEO_KHZ800);
Adafruit_NeoPixel ledStrip37(LED37_COUNT, LED_PIN_37, NEO_GRB + NEO_KHZ800);

LedRuntimeConfig ledRight = { true, 40, 246, 255, 70, LED_PATTERN_FIXED, 45 };
LedRuntimeConfig ledLeft  = { true, 40, 246, 255, 70, LED_PATTERN_FIXED, 45 };
LedRuntimeConfig ledExtra = { false, 255, 79, 227, 60, LED_PATTERN_RUNNING, 45 };
bool ledLinkSides = true;
uint32_t lastLedUpdateMs = 0;
uint32_t ledFrame = 0;
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

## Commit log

2026-07-31 document added
    [halleffect.step]
2026-07-31 Hardware Files Added
    [halleffect.step]
2026-08-02 Enclosure Files
    [Base_Final_Design.SLDPRT, Caster full kit.SLDASM, Caster wheel holder.SLDPRT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]
